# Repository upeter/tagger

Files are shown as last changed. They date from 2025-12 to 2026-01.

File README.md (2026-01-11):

# ESP32 RC Combat Vehicle with Laser Tag
> PS4-controlled robotic battle platform

An ESP32-based remote-controlled combat vehicle combining motorized movement with laser tag functionality. The system is controlled via PS4 gamepad over Bluetooth and features infrared shooting capabilities, LED visual feedback, and motor chaos effects when hit.

## Demo Video

https://github.com/user-attachments/assets/5d45b09d-6281-4fc0-92ea-92ab8f06c85d

## Features

### Core Capabilities
* **PS4 Gamepad Control**: Wireless Bluetooth control with two joystick modes (one-stick and two-stick driving)
* **Motor Control**: Dual motor drive with expo curves, deadzone handling, and pivot turning
* **Laser Tag Combat**: Infrared transmitter/receiver for shooting and detecting hits
* **Visual Laser**: Physical laser pointer activated with triggers
* **Activity Lighting**: 67 RGB LEDs (WS2812/NeoPixel) for team colors, hit indicators, and game status
* **Hit Reactions**: Motor chaos mode activated when hit, disrupting vehicle control temporarily
* **Team System**: Multiple team color support with in-game color switching

### Control Modes
* **One-stick mode**: Single joystick controls both movement and turning
* **Two-stick mode**: Left stick for forward/backward, right stick for turning with pivot-in-place and high-speed turn boost

### Game Mechanics
* Hit detection with cooldown periods
* Fire rate limiting
* Team-based combat with color identification
* Game over state when hit too many times

## Hardware Components

Use an image search to find the best deal for every component.

| Component | Description | Image |
|---|---|---|
| **ESP32 Development Board** | Main microcontroller - handles all logic, Bluetooth communication, and I/O control | ESP32 |
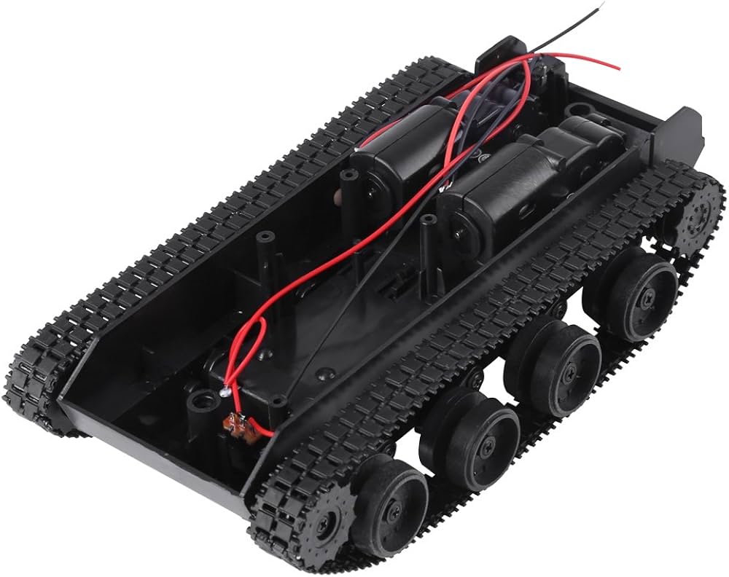
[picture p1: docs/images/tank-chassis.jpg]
Tank Chassis
| **Tank Chassis / Motors** | Tank/tracked vehicle chassis with dual DC motors for independent left/right control |  |
| **Motor Driver (L298N)** | H-bridge driver board module for controlling motor speed and direction | L298N Driver |
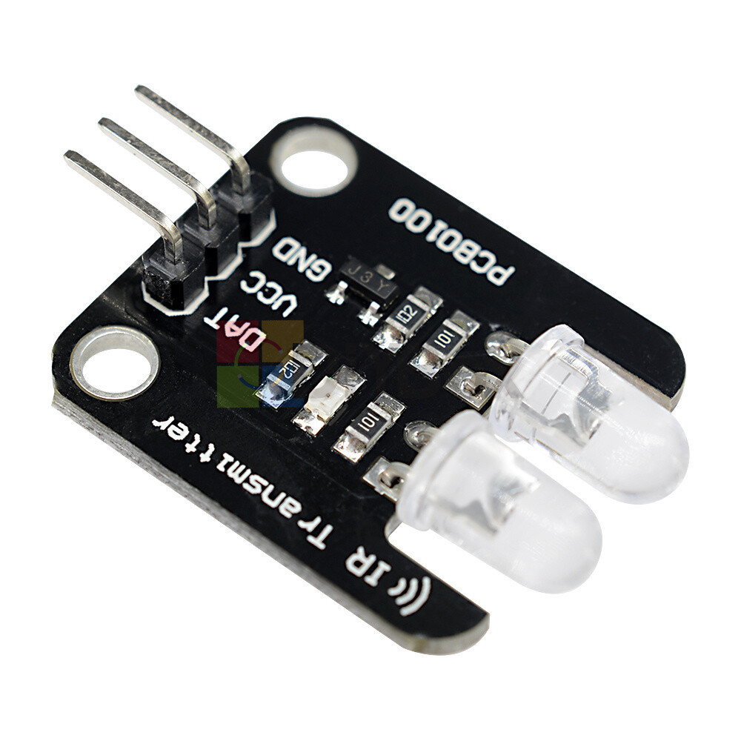
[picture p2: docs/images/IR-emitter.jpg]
IR Emitter
| **IR LED (TSUS 5202)** | 950nm infrared transmitter for shooting opponents |  |
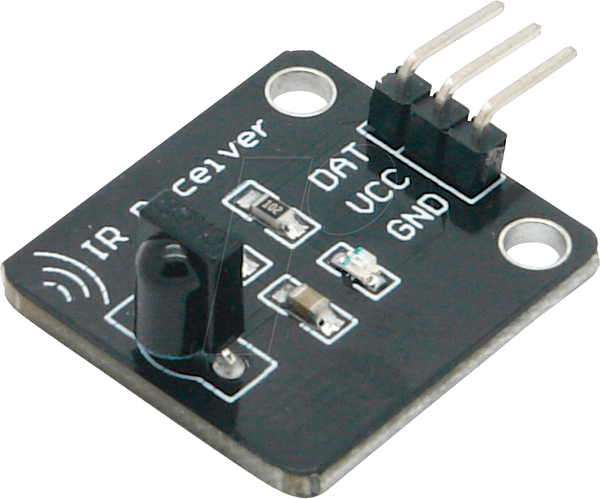
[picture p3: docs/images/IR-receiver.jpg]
IR Receiver
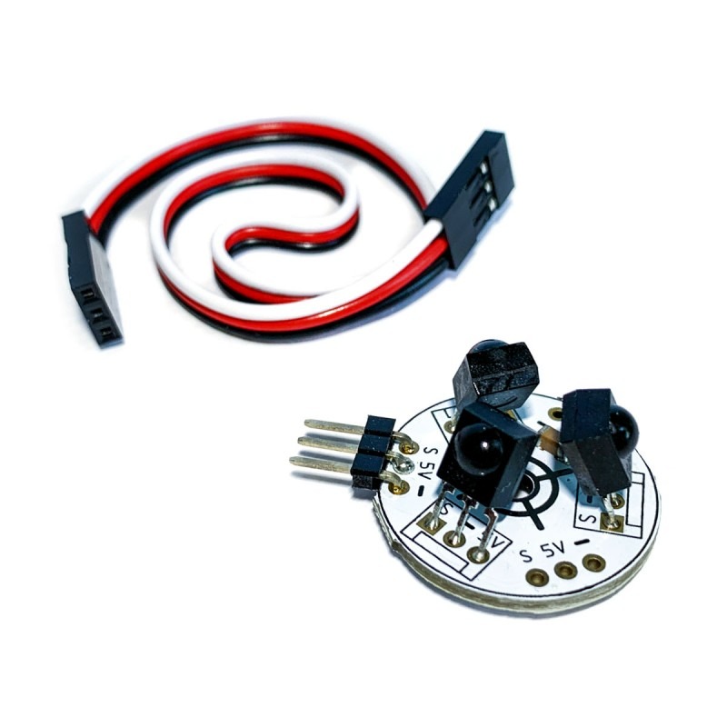
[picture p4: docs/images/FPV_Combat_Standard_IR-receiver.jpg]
FPV Standard IR Receiver
| **IR Receivers (TSOP31238)** | Two sensors (front & back) to detect incoming IR hits |    |
| **Laser Diode Module** | Visible laser pointer for aiming (GPIO 15) | Laser |
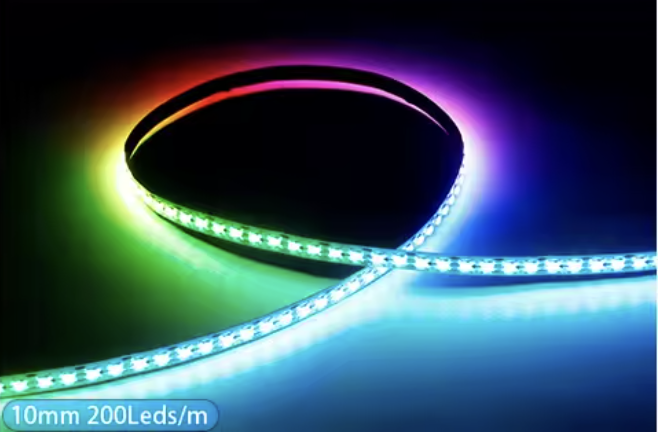
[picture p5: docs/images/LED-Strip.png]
LED Strip
| **LED Strip (WS2812)** | 67 RGB addressable LEDs for team colors and status indicators (Search for: 5mm WS2812B 2020SMD RGBIC LED-strip Ultra-small WS2812 individual addressable DC5V) |  |
| **FPV Camera + TX** | Piggyback Micro AIO FPV-camera 5.8G 40CH OSD SmartAudio 25-400 mW 600TVL NTSC 120 F. Important: the FPV TX must support 25mW, everything higher won't work in a living room with multiple FPV TX's. So use 25mW only. | FPV Camera + TX |
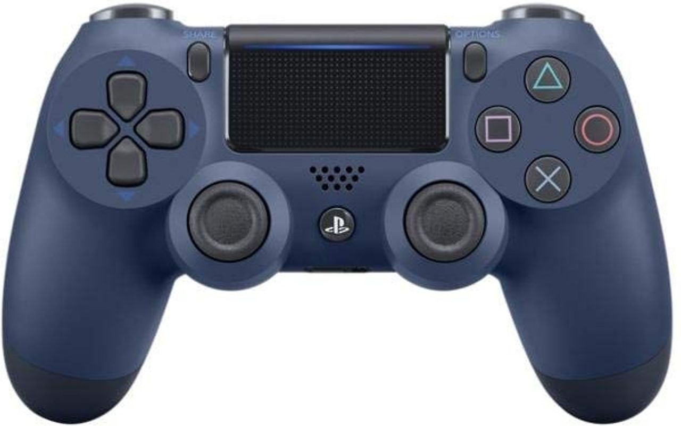
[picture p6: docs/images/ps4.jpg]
PS4
| **PS4 DualShock Controller** | Wireless Bluetooth gamepad for vehicle and combat control |  |
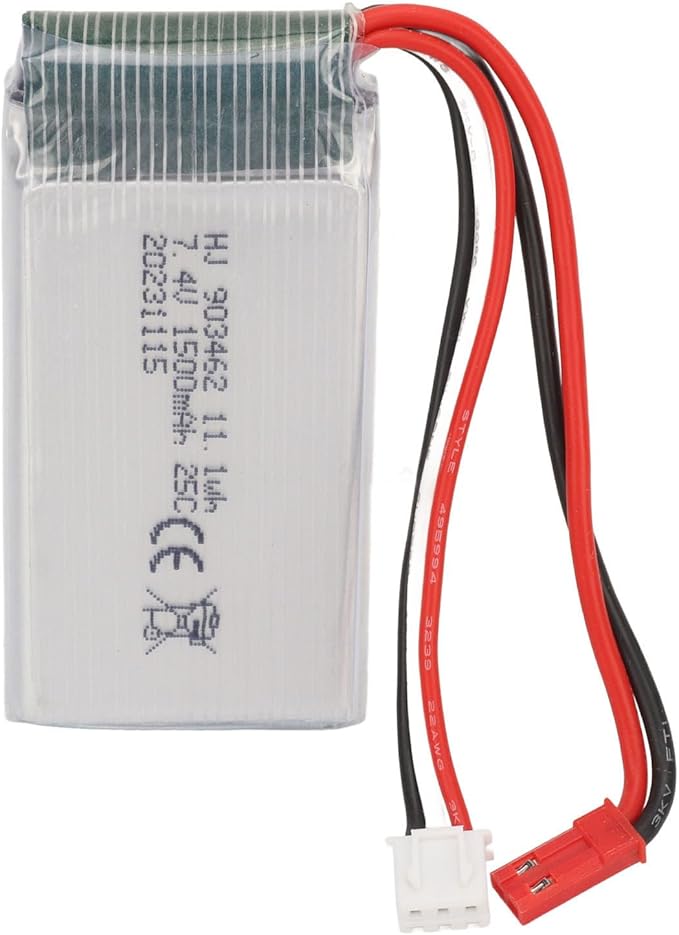
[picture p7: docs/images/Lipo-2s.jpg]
2s
| **2S LiPo Battery** | 7.4V 1200mAh - 1800mAh battery (1600 mAh gives you ~30 min runtime) |   |

### Pin Configuration
| Component | GPIO Pin |
|---|---|
| LED Strip Data | 13 |
| IR Transmit (Fire) | 2 |
| IR Receiver Front | 27 |
| IR Receiver Back | 26 |
| Laser | 15 |
| **Right Motor** | |
| Right Motor Enable | 22 |
| Right Motor Pin 1 | 16 |
| Right Motor Pin 2 | 17 |
| **Left Motor** | |
| Left Motor Enable | 23 |
| Left Motor Pin 1 | 18 |
| Left Motor Pin 2 | 19 |

## 3D Model Files

The `3d/` directory contains Fusion 360 (.f3d) design files and STL exports for mounting the ESP32 and components onto the tank chassis. Click the STL links to view interactive 3D previews on GitHub.

| Component | Description | Files |
|---|---|---|
| **Barrel** | Barrel mount for the IR LED transmitter and laser module | [.f3d](3d/Esp32TankBarrel.f3d) \| [.stl](3d/Esp32TankBarrel.stl) |
| **Chassis Plate** | Main mounting plate for ESP32, motor driver, and electronics | [.f3d](3d/Esp32TankChassisPlate.f3d) \| [.stl](3d/Esp32TankChassisPlate.stl) |
| **Chassis Plate Rails** | Rail system for attaching components to the chassis plate | [.f3d](3d/Esp32TankChassisPlateRails.f3d) \| [.stl](3d/Esp32TankChassisPlateRails.stl) |
| **Turret** | Turret assembly for mounting sensors and barrels with rotation capability | [.f3d](3d/Esp32TankTurret.f3d) \| [.stl](3d/Esp32TankTurret.stl) |

The .f3d files can be opened and modified in Autodesk Fusion 360. The .stl files are ready for 3D printing.

## Development

### VS Code with PlatformIO (Recommended)
This project is set up for VS Code with the PlatformIO extension.

**Setup:**
1. Install [VS Code](https://code.visualstudio.com/)
2. Install the PlatformIO IDE extension from the VS Code marketplace
3. Open this project folder in VS Code
4. PlatformIO will automatically detect `platformio.ini` and install dependencies

**Building and uploading:**
- Click the PlatformIO toolbar icon (checkmark) to build
- Click the upload icon (arrow) to flash to ESP32
- Or use the command palette: `PlatformIO: Upload`

### PlatformIO CLI
If you prefer the command line:

**Building and uploading:**
```bash
platformio run --target upload
```

**Monitoring serial output:**
```bash
platformio device monitor
```

### Dependencies
The project uses the following libraries (auto-installed by PlatformIO):
* NeoPixelBus - Advanced LED control
* PS4_Controller_Host - PS4 gamepad support

### PS4 Controller Setup
1. Find your ESP32's MAC address (use included `showMacAddress.cpp` utility)
2. Pair your PS4 controller using a PC/smartphone app (search for (SixAxisPairTool)[https://docs.totemmaker.net/assets/files/sixaxis/SixaxisPairToolSetup-0.3.1.exe] must have sha256 hash: b274dfc581adbf50787b6498c2e6878447e2ebe0be78c296795295b91991c2f6)
3. Set the controller's master address to your ESP32's MAC address
4. Power on the controller - it should connect automatically

## PS4 Gamepad Controls

### Movement
* **Right Stick** (one-stick mode): Forward/backward/left/right - combined movement
* **Left Stick** (two-stick mode): Forward/backward movement
* **Right Stick** (two-stick mode): Turning and pivot-in-place

### Combat
* **R1 / RB**: Fire infrared shot + activate laser
* **L1 / LB**: Activate laser without firing

### Team Selection
* **Square / X**: Pink team
* **Cross / A**: Blue team  
* **Circle / B**: Orange team
* **Triangle / Y**: Green team

### Settings
* **D-Pad Up**: Toggle joystick mode (one-stick ↔ two-stick)
* **Share**: Reset preferences to defaults
* **L2 + R2** (held together): In-game preferences reset

## Architecture

### Software Components
* **main_control**: Core game logic and FreeRTOS task management
* **PS4_gamepad**: PS4 controller interface abstraction
* **motor_control**: Dual motor mixing with expo curves and driving modes
* **motors**: Low-level motor driver interface
* **ir_fire / ir_sensors**: Infrared transmission and reception using ESP32 RMT peripheral
* **laser**: Laser pointer control
* **activity_lights**: LED patterns for game state feedback
* **flasher**: LED flashing effects
* **colors**: Team color definitions
* **prefs**: Persistent preferences storage (EEPROM)

The firmware uses FreeRTOS tasks for concurrent handling of:
* IR message reception
* LED animations
* Motor control
* Gamepad input processing

## Technical Details

### Infrared Protocol
Uses ESP32's RMT (Remote Control) peripheral for precise IR timing. Protocol details in `src/IR32/` library. The system transmits team-specific codes to differentiate between friendly and enemy fire.

### Motor Chaos Mode
When hit, the `MotorChaosMonkey` class temporarily interferes with motor control, creating erratic movement to simulate being "stunned" in combat.

### Preferences Storage
Game settings and team colors are persisted to EEPROM and loaded on boot.

## Debugging
Serial debugging at 115200 baud. Build flags in [platformio.ini](platformio.ini) enable ESP_LOG output:
```
-DCORE_DEBUG_LEVEL=4
-D LOG_LOCAL_LEVEL=ESP_LOG_DEBUG
```

## License
GPL-3.0 - See [LICENSE](LICENSE)

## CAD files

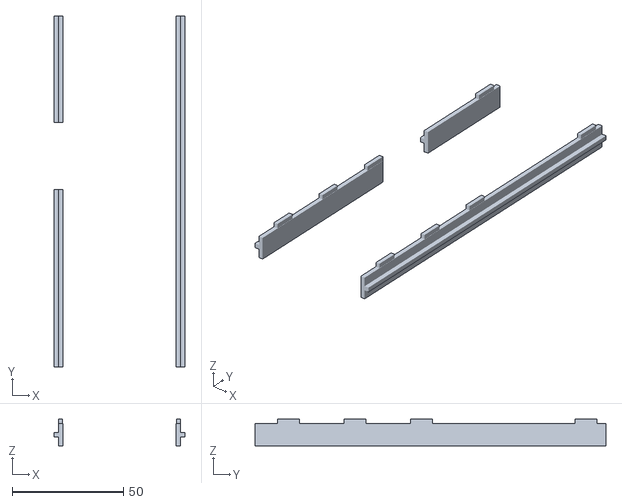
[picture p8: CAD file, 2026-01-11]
3d/Esp32TankChassisPlateRails.stl
59.0 x 158.0 x 12.0

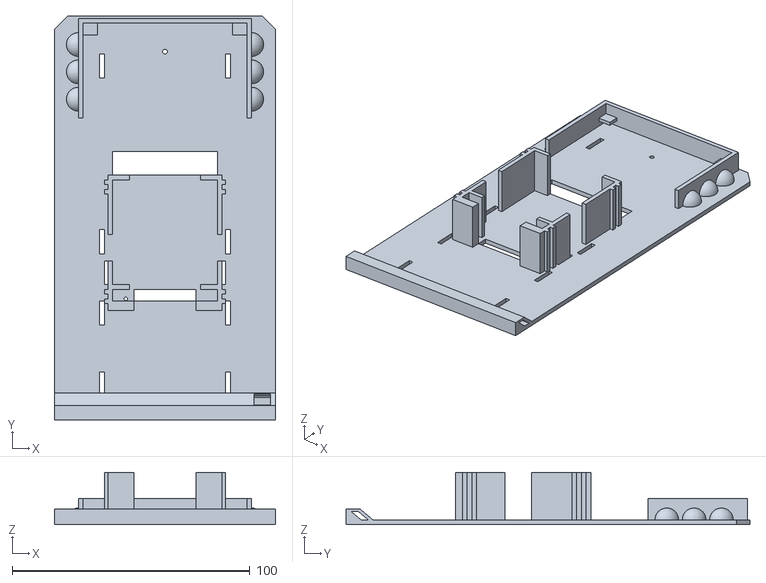
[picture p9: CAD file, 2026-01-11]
3d/Esp32TankChassisPlate.stl
93.0 x 170.0 x 22.0

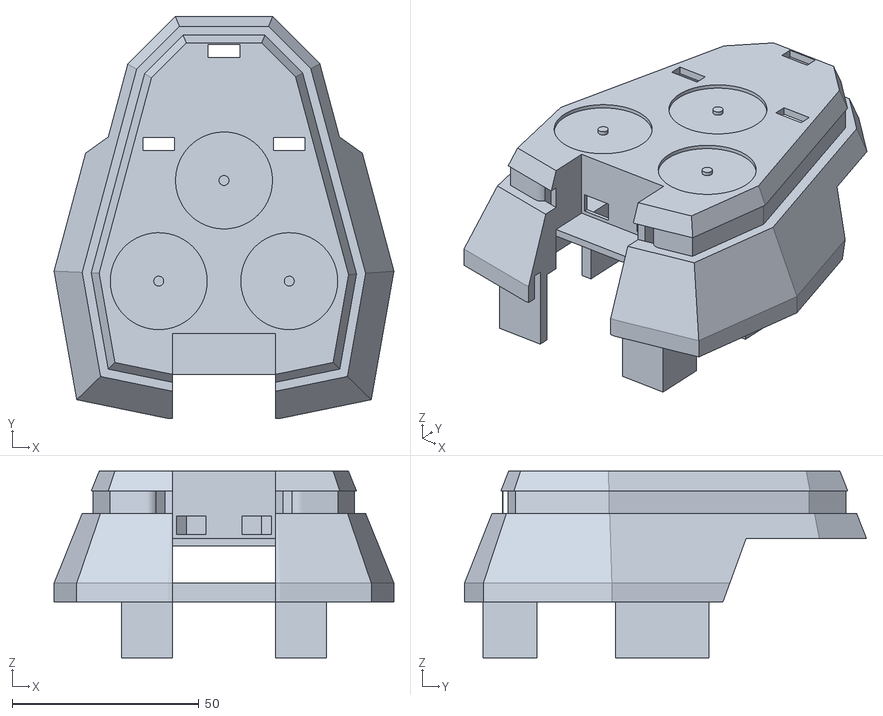
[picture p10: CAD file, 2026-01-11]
3d/Esp32TankTurret.stl
91.1 x 107.8 x 50.0

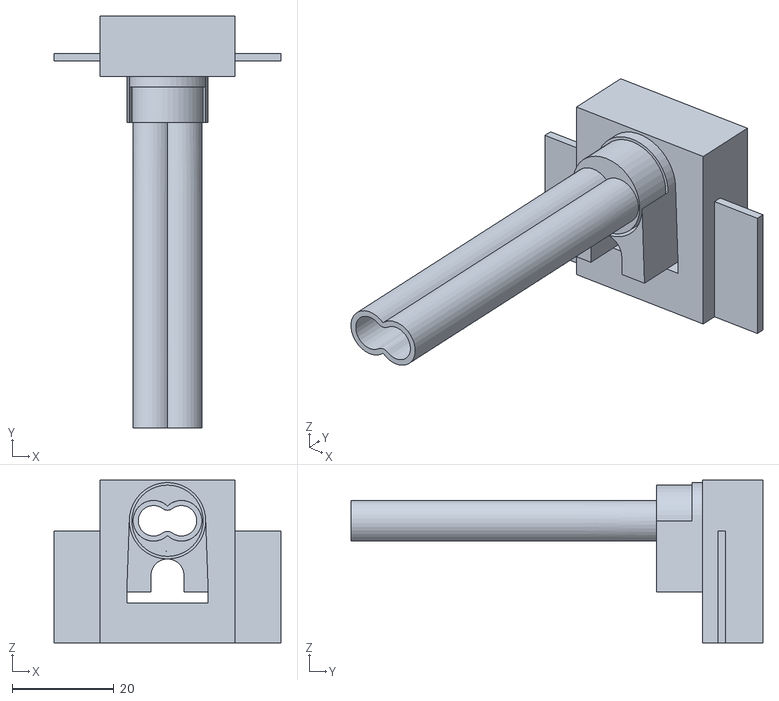
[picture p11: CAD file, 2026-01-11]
3d/Esp32TankBarrel.stl
44.6 x 80.9 x 32.0

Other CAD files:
3d/Esp32TankBarrel.f3d
3d/Esp32TankChassisPlate.f3d
3d/Esp32TankChassisPlateRails.f3d
3d/Esp32TankTurret.f3d

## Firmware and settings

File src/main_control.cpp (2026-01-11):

#include "main_control.h"

#include <Arduino.h>
#include <EEPROM.h>
#include <NeoPixelBus.h>

#include "activity_lights.h"
#include "colors.h"
#include "flasher.h"
#include "ir_fire.h"
#include "ir_sensors.h"
#include "laser.h"
#include "motor_control.h"
#include "motors.h"
#include "prefs.h"

#define LED_BUILTIN 2

// Use only core 1 for demo purposes
#if CONFIG_FREERTOS_UNICORE
static const BaseType_t app_cpu = 0;
#else
static const BaseType_t app_cpu = 1;
#endif

#define LED_DATA_PIN 13
#define NUM_LEDS 67

// Settings
static const uint8_t buf_len = 20;

// Pins
static const int led_pin = LED_BUILTIN;
static const int laser_pin = 15;

// Motor
static int maxSpeed = MOTOR_MAX_SPEED;
static int minSpeed = MOTOR_MIN_SPEED;
static volatile int trimX = 0;

static MotorControlConfig motorControlConfig;

// Globals
int led_delay = 50;   // ms
static bool flash_led = false;
static const uint32_t ir_messages[] = {
    0xFF30CF,
    0xFF18E7,
    0xFF7A85,
    0xFF10EF,
    0xFF38C7,
    0xFF5AA5,
    0xFF42BD,
    0xFF4AB5,
};

static int direction = 1;
static unsigned long lastDirectionToggleMillis = 0;
static const unsigned long DIRECTION_DEBOUNCE_MS = 500;
static Prefs currentPrefs;

// Joystick mode: 1 = one-stick (current behavior), 2 = two-stick
static uint8_t joystickMode = 1;
static unsigned long lastJoystickModeToggleMillis = 0;
static const unsigned long JOYSTICK_MODE_DEBOUNCE_MS = 500;

// Debounce for in-game prefs reset (L2+R2)
static unsigned long lastPrefsResetMillis = 0;
static const unsigned long PREFS_RESET_DEBOUNCE_MS = 2000;

static unsigned long lastTimeStamp = 0;

static TaskHandle_t xHandle_handleIR = nullptr;
static TaskHandle_t xHandle_toggleOnboardLED = nullptr;
static TaskHandle_t xHandle_triggerButton = nullptr;
static TaskHandle_t xHandle_handleLED = nullptr;

static NeoPixelBus<NeoGrbFeature,
                   NeoEsp32RmtMethodBase<NeoEsp32RmtSpeed800Kbps, NeoEsp32RmtChannel3>>
    strip(NUM_LEDS, LED_DATA_PIN);

static Motors *motors = nullptr;
static MotorChaosMonkey *chaosMonkey = nullptr;
static Flasher flasher(led_pin, 1000);
static Laser laser(laser_pin);
static ActivityLights lights(strip);

static bool onIrHit(const IREvent *event)
{
    (void)event;
    if (lights.canBeHit()) {
        vTaskResume(xHandle_toggleOnboardLED);
        lights.onHit();
        if (chaosMonkey != nullptr) {
            chaosMonkey->Start();
        }
        return true;
    }
    Serial.println(">>> Hit cooldown");
    return false;
}

static bool irCanFire()
{
    return lights.canFire();
}

static void irDidFire(uint32_t code)
{
    (void)code;
    lights.onFire();
}

static void notify(const GamepadState &state)
{
    char messageString[200];

    try {
        if (millis() - lastTimeStamp > 100) {
            int rightMotorSpeed, leftMotorSpeed;

            if (lights.isGameOver()) {
                if (motors != nullptr) {
                    motors->rotateMotor(0, 0);
                }
            } else {
                if (chaosMonkey != nullptr && chaosMonkey->isActive()) {
                    chaosMonkey->Update();
                } else {
                    if (state.r1_RB || state.l1_LB) {
                        laser.activate();
                        if (state.r1_RB) {
                            ir_fire_request(ir_messages[0]);
                        }
                    } else {
                        laser.deactivate();
                    }

                    if (state.square_X) {
                        currentPrefs = prefsWithTeamColor(currentPrefs, COLOR_PINK);
                        lights.setTeamColor(currentPrefs.color);
                    } else if (state.cross_A) {
                        currentPrefs = prefsWithTeamColor(currentPrefs, COLOR_BLUE);
                        lights.setTeamColor(currentPrefs.color);
                    } else if (state.circle_B) {
                        currentPrefs = prefsWithTeamColor(currentPrefs, COLOR_ORANGE);
                        lights.setTeamColor(currentPrefs.color);
                    } else if (state.triangle_Y) {
                        currentPrefs = prefsWithTeamColor(currentPrefs, COLOR_GREEN);
                        lights.setTeamColor(currentPrefs.color);
                    } else if (state.l2_LT && state.r2_RT) {
                        // Reset all user preferences when L2 and R2 are pressed together, with debounce
                        unsigned long now = millis();
                        if (now - lastPrefsResetMillis > PREFS_RESET_DEBOUNCE_MS) {
                            Serial.println("Resetting user preferences (L2+R2)");
                            prefsClearAll();
                            currentPrefs = prefsLoad();
                            // Re-apply any restored prefs to runtime state
                            if (currentPrefs.hasColor) {
                                lights.setTeamColor(currentPrefs.color);
                            }
                            if (currentPrefs.hasDirection) {
                                direction = currentPrefs.direction;
                            }
                            if (currentPrefs.hasJoystickMode) {
                                joystickMode = currentPrefs.joystickMode;
                            }
                            // force immediate visual refresh after prefs reset
                            lights.updateFrame();
                            lights.renderFrame();
                            lastPrefsResetMillis = now;
                        }
                    } else if (state.up) {
                        unsigned long now = millis();
                        if (now - lastDirectionToggleMillis > DIRECTION_DEBOUNCE_MS) {
                            direction = direction * -1;
                            currentPrefs = prefsWithDirection(currentPrefs, direction);
                            lastDirectionToggleMillis = now;
                        }
                    } else if (state.left) {
                        unsigned long now = millis();
                        if (now - lastJoystickModeToggleMillis > JOYSTICK_MODE_DEBOUNCE_MS) {
                            joystickMode = 2; // two-stick mode
                            currentPrefs = prefsWithJoystickMode(currentPrefs, joystickMode);
                            Serial.println("Joystick mode set to TWO-STICK (PS.Left)");
                            lastJoystickModeToggleMillis = now;
                        }
                    } else if (state.right) {
                        unsigned long now = millis();
                        if (now - lastJoystickModeToggleMillis > JOYSTICK_MODE_DEBOUNCE_MS) {
                            joystickMode = 1; // one-stick mode
                            currentPrefs = prefsWithJoystickMode(currentPrefs, joystickMode);
                            Serial.println("Joystick mode set to ONE-STICK (PS.Right)");
                            lastJoystickModeToggleMillis = now;
                        }
                    }

                    MotorControlInput controlInput;
                    controlInput.lStickX = state.lStickX;
                    controlInput.lStickY = state.lStickY * direction;
                    controlInput.rStickX = state.rStickX;
                    controlInput.rStickY = state.rStickY * direction;
                    controlInput.joystickMode = joystickMode;

                    motorControlConfig.trimX = trimX;
                    MotorControlOutput cmd = motorControlCompute(controlInput, motorControlConfig);
                    rightMotorSpeed = cmd.rightMotorSpeed;
                    leftMotorSpeed = cmd.leftMotorSpeed;

                    if (motors != nullptr) {
                        motors->rotateMotor(rightMotorSpeed, leftMotorSpeed);
                    }
                }
            }

            lastTimeStamp = millis();
        }
    } catch (const std::exception &e) {
        Serial.print("Exception caught: ");
        Serial.println(e.what());
    }
}

void main_control_onConnect()
{
    Serial.println("Connected!.");
}

void main_control_onDisconnect()
{
    if (motors != nullptr) {
        motors->rotateMotor(0, 0);
    }
    Serial.println("Disconnected!.");
}

// Task: Blink LED at rate set by global variable
static void toggleOnboardLED(void *parameter)
{
    (void)parameter;
    while (true) {
        vTaskSuspend(NULL);
        flasher.flash();
    }
}

static void handleLED(void *parameter)
{
    (void)parameter;
    const TickType_t frameDelay = pdMS_TO_TICKS(20);
    while (true) {
        lights.updateFrame();
        lights.renderFrame();
        vTaskDelay(frameDelay);
    }
}

void main_control_setup(Gamepad &gamepad)
{
    // Configure pin
    pinMode(led_pin, OUTPUT);

    // Configure serial and wait a second
    Serial.begin(115200);
    vTaskDelay(1000 / portTICK_PERIOD_MS);
    Serial.println("Initializing tank");
    Serial.println("Initializing onboard LEDs...");

    // Start blink task
    xTaskCreatePinnedToCore(toggleOnboardLED,
                            "Toggle LED",
                            2048,
                            NULL,
                            1,
                            &xHandle_toggleOnboardLED,
                            1);

    vTaskDelay(1000);
    strip.Begin();
    strip.Show();

    Serial.println("Initialize motors...");

    motors = new Motors();
    chaosMonkey = new MotorChaosMonkey(motors);
    motors->setUpPinModes();
    Serial.println("Motors initialized");

    motorControlConfig = motorControlDefaultConfig(minSpeed, maxSpeed);

    // Load user preferences (team color + direction)
    currentPrefs = prefsLoad();
    if (currentPrefs.hasColor) {
        lights.setTeamColor(currentPrefs.color);
    }
    if (currentPrefs.hasDirection) {
        direction = currentPrefs.direction;
    }
    if (currentPrefs.hasJoystickMode) {
        joystickMode = currentPrefs.joystickMode;
    }

    // Ensure LEDs reflect initial state
    lights.updateFrame();
    lights.renderFrame();

    // Start IR subsystems once lights + motors are ready
    ir_sensors_begin(onIrHit);
    ir_fire_begin(irCanFire, irDidFire);

    // Start LED task
    xTaskCreatePinnedToCore(handleLED,
                            "handle LED",
                            4096,
                            NULL,
                            2,
                            &xHandle_handleLED,
                            1);

    // Gamepad callbacks (transport-specific begin/connect hooks happen in wrapper)
    gamepad.attach(notify);
	gamepad.attachOnConnect(main_control_onConnect);
	gamepad.attachOnDisconnect(main_control_onDisconnect);
	gamepad.begin();


    Serial.println("Main control initialized");
}

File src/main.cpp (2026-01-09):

/**
 * Solution to 03 - LED Challenge
 * 
 * One task flashes an LED at a rate specified by a value set in another task.
 * 
 * Date: December 4, 2020
 * Author: Shawn Hymel
 * License: 0BSD
 */

#include <Arduino.h>

#include "PS4_gamepad.h"
#include "main_control.h"

static PS4Gamepad gamepad;

void setup()
{
	main_control_setup(gamepad);

	// Delete "setup and loop" task
	vTaskDelete(NULL);
}

void loop()
{
	// Execution should never get here
	vTaskDelay(portMAX_DELAY);
}

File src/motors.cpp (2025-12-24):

#include "motors.h"

// Define motor configuration constants (matching previous globals)
const int MOTOR_MAX_SPEED = 255;
const int MOTOR_MIN_SPEED = -MOTOR_MAX_SPEED;

// Right motor
const int ENABLE_RIGHT_MOTOR_PIN = 22;
const int RIGHT_MOTOR_PIN1 = 16;
const int RIGHT_MOTOR_PIN2 = 17;

// Left motor
const int ENABLE_LEFT_MOTOR_PIN = 23;
const int LEFT_MOTOR_PIN1 = 18;
const int LEFT_MOTOR_PIN2 = 19;

// PWM
const int MOTOR_PWM_FREQ = 1000; /* 1 KHz */
const int MOTOR_PWM_RESOLUTION = 8;
const int RIGHT_MOTOR_PWM_CHANNEL = 4;
const int LEFT_MOTOR_PWM_CHANNEL = 5;

void Motors::setMotorDirections(int motorPin1, int motorPin2, int speed)
{
    int pin1State = (speed > 0) ? HIGH : LOW;
    int pin2State = (speed < 0) ? HIGH : LOW;

    digitalWrite(motorPin1, pin1State);
    digitalWrite(motorPin2, pin2State);
}

void Motors::rotateMotor(int rightMotorSpeed, int leftMotorSpeed)
{
    setMotorDirections(RIGHT_MOTOR_PIN1, RIGHT_MOTOR_PIN2, rightMotorSpeed);
    setMotorDirections(LEFT_MOTOR_PIN1, LEFT_MOTOR_PIN2, leftMotorSpeed);
    ledcWrite(RIGHT_MOTOR_PWM_CHANNEL, abs(rightMotorSpeed));
    ledcWrite(LEFT_MOTOR_PWM_CHANNEL, abs(leftMotorSpeed));
}

void Motors::setUpPinModes()
{
    pinMode(ENABLE_RIGHT_MOTOR_PIN, OUTPUT);
    pinMode(RIGHT_MOTOR_PIN1, OUTPUT);
    pinMode(RIGHT_MOTOR_PIN2, OUTPUT);

    pinMode(ENABLE_LEFT_MOTOR_PIN, OUTPUT);
    pinMode(LEFT_MOTOR_PIN1, OUTPUT);
    pinMode(LEFT_MOTOR_PIN2, OUTPUT);

    // Set up PWM for motor speed
    ledcSetup(RIGHT_MOTOR_PWM_CHANNEL, MOTOR_PWM_FREQ, MOTOR_PWM_RESOLUTION);
    ledcSetup(LEFT_MOTOR_PWM_CHANNEL, MOTOR_PWM_FREQ, MOTOR_PWM_RESOLUTION);
    ledcAttachPin(ENABLE_RIGHT_MOTOR_PIN, RIGHT_MOTOR_PWM_CHANNEL);
    ledcAttachPin(ENABLE_LEFT_MOTOR_PIN, LEFT_MOTOR_PWM_CHANNEL);

    rotateMotor(0, 0);
}

MotorChaosMonkey::MotorChaosMonkey(Motors *motors_)
{
    motors = motors_;
}

void MotorChaosMonkey::Start()
{
    unsigned long currentMillis = millis();
    if (!active && (currentMillis - startMillis) >= coolDownMillis)
    {
        active = true;
        startMillis = millis();
        Serial.println((String)"chaos started");
    }
    else
    {
        Serial.println((String)"chaos won't start because it is already active");
    }
}

bool MotorChaosMonkey::isActive()
{
    return active;
}

void MotorChaosMonkey::Update()
{
    unsigned long currentMillis = millis();
    if (active)
    {
        if ((currentMillis - startMillis) >= chaosDurationMillis)
        {
            active = false;
            startMillis = 0;
            phaseOneExecuted = false;
            phaseTwoExecuted = false;
            Serial.println((String)"chaos terminated after: " + chaosDurationMillis);
        }
        else
        {
            if (!phaseOneExecuted)
            {
                motors->rotateMotor(MOTOR_MAX_SPEED, -MOTOR_MAX_SPEED);
                phaseOneExecuted = true;
            }
            if (phaseOneExecuted && !phaseTwoExecuted && currentMillis - startMillis >= (chaosDurationMillis / 2))
            {
                motors->rotateMotor(-MOTOR_MAX_SPEED, MOTOR_MAX_SPEED);
                phaseTwoExecuted = true;
            }
        }
    }
}

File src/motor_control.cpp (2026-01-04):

#include "motor_control.h"

static float withExpo(int x, float expo, float nullFactor)
{
	if (x == 0) {
		return 1.0f;
	}
	x = abs(x);
	float n = (float(x)) / nullFactor;
	float y = expo * powf(n, 3) + ((1.0f - expo) * n);
	return y;
}

MotorControlConfig motorControlDefaultConfig(int minSpeed, int maxSpeed)
{
	MotorControlConfig cfg;
	cfg.minSpeed = minSpeed;
	cfg.maxSpeed = maxSpeed;
	cfg.trimX = 0;
	cfg.maxX = 35;
	cfg.expo = 0.5f;
	cfg.nullFactor = 157.0f;
	cfg.turnGain = 5.0f;
	cfg.deadzone = 10;
	cfg.standstillThreshold = 10;
	cfg.pivotScale = 1.5f;
	cfg.highThrottleThreshold = 80;
	cfg.highThrottleTurnBoost = 2.5f;
	return cfg;
}

MotorControlOutput motorControlCompute(const MotorControlInput &input, const MotorControlConfig &config)
{
	MotorControlOutput out;
	out.rightMotorSpeed = 0;
	out.leftMotorSpeed = 0;
	out.rightMotorSpeedRaw = 0;
	out.leftMotorSpeedRaw = 0;

	int stickY = 0;
	int stickX = 0;

	if (input.joystickMode == 2) {
		// Two-stick: left Y for forward/back, right X for turning
		// Use right X for in-place spins when no forward/back input
		int rawY = input.lStickY;
		int rawTurn = input.rStickX;
		int rawSpin = input.rStickY;

		if (abs(rawY) < config.deadzone && abs(rawSpin) < config.deadzone) {
			// Standing still: steering stick should rotate in place
			stickY = 0;
			stickX = rawTurn;
		} else {
			// Moving: left Y + right X mixed driving
			stickY = rawY;
			stickX = rawTurn;
		}
	} else {
		// One-stick: right stick controls both
		stickY = input.rStickY;
		stickX = input.rStickX;
	}

	float stickXExpo = withExpo(stickX, config.expo, config.nullFactor);
	int stickXWithExpo = constrain(
		(int)(((float(stickX) * stickXExpo) * config.turnGain + config.trimX) * -1),
		-config.maxX,
		config.maxX);

	if (input.joystickMode == 2 && abs(stickY) < config.standstillThreshold) {
		// Pivot in place
		int rawTurn = input.rStickX; // -127..127
		int pivot = constrain((int)(rawTurn * config.pivotScale), -127, 127);

		out.rightMotorSpeedRaw = pivot;
		out.leftMotorSpeedRaw = -pivot;
	} else if (input.joystickMode == 2 && abs(stickY) > config.highThrottleThreshold) {
		// At high throttle in 2-stick mode, boost turning for tighter curves
		int boostedTurn = constrain((int)(stickXWithExpo * config.highThrottleTurnBoost), -config.maxX, config.maxX);
		out.rightMotorSpeedRaw = constrain(stickY - boostedTurn, -127, 127);
		out.leftMotorSpeedRaw = constrain(stickY + boostedTurn, -127, 127);
	} else {
		out.rightMotorSpeedRaw = constrain(stickY - stickXWithExpo, -127, 127);
		out.leftMotorSpeedRaw = constrain(stickY + stickXWithExpo, -127, 127);
	}

	out.rightMotorSpeed = (int)map(out.rightMotorSpeedRaw, -127, 127, config.minSpeed, config.maxSpeed);
	out.leftMotorSpeed = (int)map(out.leftMotorSpeedRaw, -127, 127, config.minSpeed, config.maxSpeed);

	out.rightMotorSpeed = constrain(out.rightMotorSpeed, config.minSpeed, config.maxSpeed);
	out.leftMotorSpeed = constrain(out.leftMotorSpeed, config.minSpeed, config.maxSpeed);

	return out;
}

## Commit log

2023-10-29 Trigger combat board
2024-09-27 no pwm for fpv shooting
2024-12-07 Working version with LED & IR
2024-12-07 samples for show mac address and PS4 controller
    compatibility
2024-12-07 Motor integrated
2025-01-10 Laserpin and chaos monkey
2025-01-11 led handling
2025-01-14 working version with laser - new pins for laser and IR receiver
2025-01-22 replace isHitActive with timing approach, Up button to change direction
    [main.cpp]
2025-12-01 Updates hardware config for ESP32-S3 support
    Switches platform and board settings to target ESP32-S3.
    Reassigns RMT channels for IR and LED control to align
    with ESP32-S3 hardware requirements and avoid conflicts.
    Improves compatibility with new board and peripheral layout.
    [main.cpp]
2025-12-01 Reset to esp32
2025-12-07 Refactor color management by moving color definitions to separate files and adding user preference reset functionality
    [main.cpp, prefs.cpp, prefs.h]
2025-12-07 Add joystick mode configuration and debounce handling for direction and preferences reset
    [main.cpp]
2025-12-08 Fix firing condition to respect invulnerability period
    [main.cpp]
2025-12-08 Major refactoring for LED strip handling with frames rather than separate loops
2025-12-24 Extract motors
2025-12-26 Extracted laser and flasher
2026-01-04 externalize IR sensor and firing subsystem with callback support
2026-01-04 Externalize motor control
2026-01-11 Add new 3D model files for Esp32 Tank components
    [Esp32TankBarrel.f3d, Esp32TankBarrel.stl, Esp32TankChassisPlate.f3d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]
